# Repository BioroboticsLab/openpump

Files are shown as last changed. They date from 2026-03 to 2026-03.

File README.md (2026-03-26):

# 🌱 OpenPump — Single-Pump Quad-Valve

An open-source, sensor-driven plant watering system built on [ESPHome](https://esphome.io/) and the ESP32. A single pump serves up to **four independent zones** via electronically controlled valves, each with its own soil-moisture sensor, adjustable dryness threshold, and cooldown timer — plus real-time **Telegram notifications**.

> **Branch:** `single_pump_quad_valve` — ESPHome YAML configuration.
> The `main` branch contains the original bare-metal ESP-IDF C firmware for a single-sensor setup.

## Features

- **4-zone watering** — one pump, four valves, four capacitive soil-moisture sensors
- **Per-zone thresholds** — adjustable dryness sliders (0–100) via Home Assistant or the built-in web UI
- **Cooldown protection** — 1-hour cooldown per zone prevents overwatering
- **Pump mutex** — only one zone can pump at a time, preventing pressure issues
- **Telegram alerts** — instant notifications when pumping starts/stops
- **Telegram bot commands** — send `status` for a full report, or `value pod 1` to query a single sensor
- **Heartbeat** — periodic uptime report via Telegram (every 2 hours)
- **Status LED** — blinks during boot/Wi-Fi reconnect, solid when connected
- **Wi-Fi events** — Telegram notification on connect; LED feedback on disconnect
- **OTA updates** — flash new firmware over Wi-Fi
- **Fallback AP** — device creates a hotspot if Wi-Fi is unavailable
- **Web dashboard** — built-in web server on port 80

## Hardware

### 3D-Printed Parts

The enclosure consists of **4 main printed parts** and **1 auxiliary part** printed once per plant zone (up to 4×):

| Part | Description |
|---|---|
| **Box** | Main enclosure: floor and two short side walls. One side wall has a socket for the buck converter with the DC barrel jack hole directly beneath it. The other side wall has a socket for the breadboard. |
| **Wall 1 (Tube Wall)** | Modular wall with half-circle cable management bridges along the top edge and **5 tube holes** at the bottom. The 3rd (middle) hole is the water intake for the pump; the remaining 4 holes are the valve outlets. |
| **Wall 2 (Relay Wall)** | Modular wall with half-circle cable management bridges along the top edge and sliding sockets for the **4-channel relay module** and the **1-channel relay module**. |
| **Lid** | Slides over the finished assembly to close the enclosure. |
| **Sensor Clamp** *(× 1 per zone, max 4)* | Inserted into a pot or reservoir. Contains a tight slot for the capacitive soil-moisture sensor and a hole to secure the outlet tube in place. |

---

### Electronic Components

| Component | Qty | Link |
|---|-----|---|
| ESP32 DevKit | 1 | [AZ-Delivery](https://www.az-delivery.de/products/esp32-nodemcu-module-wlan-wifi-dev-kit-c-development-board-mit-cp2102-und-usb-c-anschluss-esp-32-esp32-wroom-32-kompatibel-mit-ar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) |
| Breadboard (~400 pin, half-size) | 1 | [Conrad](https://www.conrad.de/de/p/velleman-steckplatine-grau-polzahl-gesamt-400-l-x-b-x-h-82-x-8-x-55-mm-1-st-2574925.html) |
| 4-channel relay module | 1 | [Conrad](https://www.conrad.de/de/p/tru-components-tc-9927216-relais-modul-1-st-2481804.html) |
| 1-channel relay module | 1 | [Conrad](https://www.conrad.de/de/p/whadda-wpm406-relais-modul-1-st-2330791.html) |
| Buck converter (12 V → 5 V) | 1 | [AZ-Delivery](https://www.az-delivery.de/products/xl4016e-yh11060d) |
| Capacitive soil-moisture sensor | up to 4 | [AZ-Delivery](https://www.az-delivery.de/products/bodenfeuchte-sensor-modul-v1-2) |
| Peristaltic pump (12 V) | 1 | [Amazon](https://www.amazon.de/Peristaltische-Mini-Peristaltikpumpe-Bioengineering-Silikonschlauch-Aquarienlaboranalytik/dp/B0BTQMRSQ8) |
| Solenoid valve (12 V, NC) | up to 4 | [Amazon](https://www.amazon.de/WITTKOWARE-Mini-Magnetventil-12V-Anschl%C3%BCsse-Positionen/dp/B07JB53SMP) |
| DC barrel jack (2.5 mm) | 1 | [Conrad](https://www.conrad.de/de/p/econ-connect-dce5bp-niedervolt-steckverbinder-chassisbuchse-gerade-2-5-mm-1-st-1303454.html) |
| 12 V / 2 A power supply | 1 | [Conrad](https://www.conrad.de/de/p/dehner-elektronik-sys-1308n-2412-w2e-steckernetzteil-festspannung-12-v-dc-2-a-24-w-stabilisiert-2330693.html) |
| Silicone tube (ID 3.5 mm / OD 4.5 mm) | as needed | any aquarium supplier |
| Spring hose clamps (4 mm) | 8 (2 per valve) | [Amazon](https://amzn.eu/d/0d3o6NUx) |
| T-profile tube connectors (3 mm) | 3 | [Amazon](https://www.amazon.de/BGS-8790-10-Schlauchverbinder-Sortiment-10-mm/dp/B015EKYP7Y) |

---

### Pin Mapping

| GPIO | Function |
|---|---|
| GPIO32 | Soil-moisture sensor 1 (ADC) |
| GPIO33 | Soil-moisture sensor 2 (ADC) |
| GPIO39 | Soil-moisture sensor 3 (ADC) |
| GPIO35 | Soil-moisture sensor 4 (ADC) |
| GPIO17 | Pump — 1-channel relay (active-HIGH) |
| GPIO22 | Valve 1 — 4-channel relay ch.1 (active-HIGH) |
| GPIO21 | Valve 2 — 4-channel relay ch.2 (active-HIGH) |
| GPIO19 | Valve 3 — 4-channel relay ch.3 (active-HIGH) |
| GPIO18 | Valve 4 — 4-channel relay ch.4 (active-HIGH) |
| GPIO2  | Status LED (active-LOW) |
| 3.3 V pin | Shared power rail for all 4 moisture sensors |

---

### Assembly Instructions

**Before you start:** Print all 4 main parts plus one Sensor Clamp per zone. Have a soldering iron, glue, and the step file open to measure the correct breadboard width for the socket.

**1. Soldering**
1. Solder 2 wires onto the DC barrel jack.
2. Solder 2 wires onto the pump.

**2. Prepare the DC barrel jack**
1. Insert the DC barrel jack into the hole beneath the buck converter socket on the side wall of the box.

**3. Prepare the breadboard**
1. Split the breadboard at the center. Before gluing, measure the correct width using the step file so the breadboard fits snugly into its socket.
2. Glue both halves onto a piece of thin cardboard, leaving a small gap so cables can be routed on both sides of the ESP32.
3. Glue the cardboard-mounted breadboard into its socket on the other side wall of the box.
4. Place the ESP32 onto the breadboard.

**4. Install the buck converter and relay modules**
1. Plug the buck converter into its socket on the box wall.
2. Slide the **4-channel relay module** and **1-channel relay module** down into their sockets in Wall 2 (Relay Wall).

**5. Install Wall 1 (Tube Wall)**
1. Fit Wall 1 before gluing the valves to the floor — this makes positioning much easier.
2. Loosely place the solenoid valves and peristaltic pump inside the box.
3. Route the pump intake tube through the **3rd (middle) hole** of Wall 1. Route the 4 valve outlet tubes through the remaining holes. Secure each valve tube with **2 spring hose clamps**.
4. Use **3 T-profile connectors (3 mm)** to split the single pump output tube into 4 lines, one for each valve inlet.

**6. Wiring — Power circuit**

Start by establishing your two power rails on the breadboard (12 V and 5 V):

1. Connect the two wires from the DC barrel jack to the **12 V + and − rows** on one side of the breadboard.
2. Run two cables from the 12 V rows to the **buck converter input** (+ and −).
3. Run the buck converter output cables to the **opposite side** of the breadboard, establishing the **5 V + and − rows**.

You now have a 12 V rail and a 5 V rail available on the breadboard.

**7. Wiring — Valves (4-channel relay module)**

Repeat for each of the 4 valves:

1. Connect the valve's **red (+) cable** directly to the **12 V + row** on the breadboard.
2. Connect the valve's **black (−) cable** to the **middle terminal (COM)** of the corresponding relay channel.
3. Connect a cable from the **right terminal (NO)** of that relay channel to the **12 V − row** on the breadboard.

Then wire the relay module's control circuit:

| Pin | Connection |
|-----|---|
| VCC | 5 V + row on breadboard |
| GND | 5 V − row on breadboard |
| IN1 | GPIO22 (Valve 1) |
| IN2 | GPIO21 (Valve 2) |
| IN3 | GPIO19 (Valve 3) |
| IN4 | GPIO18 (Valve 4) |

**8. Wiring — Pump (1-channel relay module)**

1. Connect the pump's **red (+) cable** directly to the **12 V + row** on the breadboard.
2. Connect the pump's **black (−) cable** to the **middle terminal (COM)** of the single relay.
3. Connect a cable from the **right terminal (NO)** of the relay to the **12 V − row** on the breadboard.

Then wire the relay module's control circuit:

| Pin | Connection |
|-----|---|
| VCC | 5 V + row on breadboard |
| GND | 5 V − row on breadboard |
| IN  | GPIO17 (Pump) |

**9. Wiring — Moisture sensors**

The moisture sensors run on **3.3 V**, not 5 V or 12 V:

1. Run a cable from the ESP32's **3.3 V pin** to a free horizontal row on the breadboard — this becomes your **3.3 V shared row**.
2. For each sensor, plug its **VCC cable** into that same 3.3 V row.
3. Connect each sensor's **GND cable** to the **5 V − row** (common ground).
4. Connect each sensor's **signal (AOUT) cable** to its corresponding GPIO:

| Sensor | GPIO |
|---|---|
| Sensor 1 | GPIO32 |
| Sensor 2 | GPIO33 |
| Sensor 3 | GPIO39 |
| Sensor 4 | GPIO35 |

**10. Final fixation**
1. Once all wiring is complete and verified, glue or screw the pump into position (screw holes are provided).
2. Glue the valves to there sockets.
3. Slide in the second wall (can be kind of tricky).
4. Slide the **Lid** onto the finished assembly.

**11. Install Sensor Clamps**
1. For each plant zone, insert a Sensor Clamp into the pot or reservoir.
2. Slide the moisture sensor into the tight slot.
3. Route the outlet tube through the hole in the clamp to hold it in place.

> ⚠️ **Relay polarity:** Relays are **active-HIGH** — do **not** set `inverted: true` in the ESPHome config. If the pump or a valve runs when it should be OFF, check that you are using COM/NO and not COM/NC on the relay terminals.

## Getting Started

### Prerequisites

- [ESPHome](https://esphome.io/guides/installing_esphome.html) installed (`pip install esphome`)
- A `secrets.yaml` file in the same directory as `valve.yaml`

### Secrets Setup

Create a `secrets.yaml` file alongside `valve.yaml`:
```yaml
ssid: "Your_WiFi_SSID"
password_wifi: "Your_WiFi_Password"
password_ap: "FallbackHotspotPassword"
telegram_bot_token: "123456:ABC-DEF..."
telegram_chat_id: "-100123456789"
api_key: "your-base64-encryption-key"      # generate with: openssl rand -base64 32
ota_password: "a-secure-ota-password"
```

> **Tip:** Create a Telegram bot via [@BotFather](https://t.me/BotFather) and get your chat ID via [@userinfobot](https://t.me/userinfobot).

### Flash the ESP32
```bash
# Validate the configuration
esphome config valve.yaml

# Compile and upload (first time — via USB)
esphome run valve.yaml

# Subsequent updates can be done OTA
esphome run valve.yaml --device labor.local

# Or use the helper script
./flash.sh                              # default: valve.yaml → labor.local
./flash.sh tests/test_actuators.yaml     # flash a test config
./flash.sh valve.yaml 10.94.201.232      # flash to a specific IP
```

### Home Assistant

The device advertises itself via the ESPHome native API. In Home Assistant, go to **Settings → Devices & Services** — the device `labor` should appear for automatic adoption.

## How It Works

1. **Every 30 seconds**, the system checks each zone sequentially.
2. If a zone's moisture reading is **below its threshold** and the **cooldown has expired** and the **pump is not busy**, watering begins:
   - All other valves are closed.
   - The zone's valve opens.
   - The pump runs for the configured **pump duration** (default 30 s, adjustable 5–120 s via slider).
   - A Telegram message is sent at start and stop.
3. A **1-hour cooldown** prevents the same zone from being watered again too soon.
4. The `pump_busy` flag ensures only one zone can pump at a time.
5. A **heartbeat** message is sent via Telegram every 2 hours with the device's uptime.
6. The **Telegram bot** polls for incoming commands every 5 seconds — send `status` for a full report (all sensors, thresholds, cooldowns, pump state, uptime), or `value pod 1` through `value pod 4` for a single reading.
7. The **status LED** blinks during boot and Wi-Fi reconnect, and stays solid once connected.
8. If a zone stays **dry for 24 hours**, a persistent dry alert is sent via Telegram.

## Sensor Calibration

The sensors output a raw ADC voltage which is scaled (×100) and then linearly mapped to 0–100 % using:
```
y = -0.53125 × x + 111.25
```

This maps approximately 21 → 100 % (wet) and 209 → 0 % (dry). To tune for your sensors, adjust the formula coefficients in the `lambda` filter of each sensor in `valve.yaml`.

## Project Structure
```
openpump/
├── valve.yaml                    # ESPHome configuration (main file)
├── secrets.yaml                  # Wi-Fi & Telegram credentials (not tracked)
├── flash.sh                      # Build + OTA flash helper script
├── tests/
│   ├── secrets.yaml              # → symlink to ../secrets.yaml
│   ├── test_actuators.yaml       # Minimal pump/valve toggle test
│   ├── test_sensors.yaml         # Sensor + actuator test
│   └── test_gpio_scan.yaml       # All ADC1 GPIO scan
├── LICENSE                       # MIT
└── README.md                     # This file
```

## License

Licensed under the [MIT License](LICENSE).

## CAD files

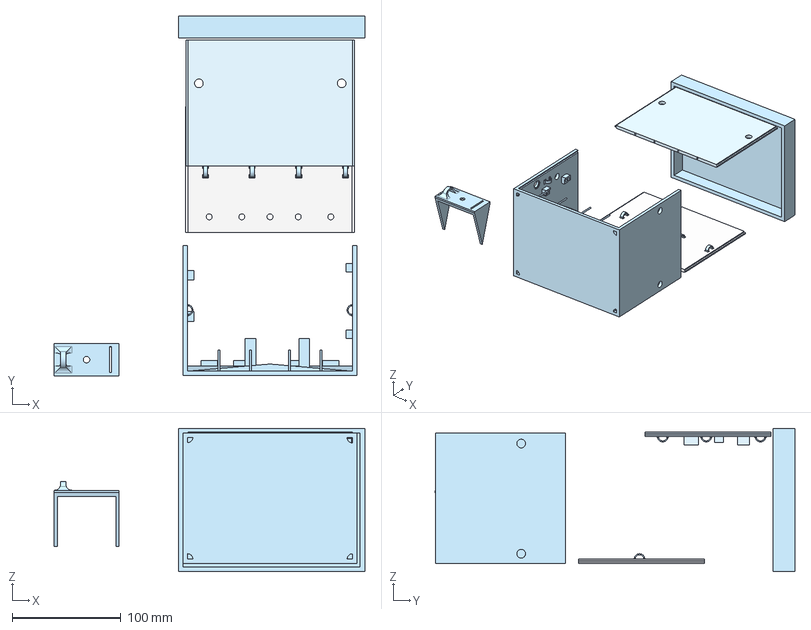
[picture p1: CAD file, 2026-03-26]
box_assembly.step
286.5 x 331.5 x 132.0 mm
Wandmodular 2
Wandmodular 1

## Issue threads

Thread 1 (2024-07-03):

Add switch(es) for manual pump and on-off or auto-manual

timlandgraf, 2024-07-03:
In the current design, you switch the pump on by plugging it into the wall. The device should have an on / off (or automatic / manual) switch, and once we are adding this we could also add buttons for pumping in one or the other direction. This could prove useful in a practical setting. Needs a concept how these switches / buttons behave.

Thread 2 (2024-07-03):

Add status LED(s)

timlandgraf, 2024-07-03:
It would be nice to know in which state the system is currently:

* on / off or automatic / manual mode
* pumping (in case the motor is dead you would still see that the ESP is trying to pump)
* direction of pumping
* errors (like being in failsafe state after motor has been running longer than x seconds)
* warnings (like when the sensor is close to the threshold. once the electrodes are corroded, we can't detect when they're in water anymore)

needs a concept how to encode these things with a minimal number of LEDs

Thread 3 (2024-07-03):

Add sensor for source container

timlandgraf, 2024-07-03:
Currently, the pump stops pumping only when there is water (or whatever liquid you are using) on the sensor. Once the source container is emptied, the pump would pump indefinitely and is only stopped by a failsafe mechanism (a timer). Would be nice if the pump would be able to detect if the contained has been refilled and then starts pumping again.

mirsada, 2024-07-03:
Bluetooth - Feuchtigkeitssensor Xiami Miflora  oder andere Sensoren verwenden ?

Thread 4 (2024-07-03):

OpenPump

mirsada, 2024-07-03:
Als Grundlage für dieses Projekt  dient ein 3D gedrucktes Trink- Gehäuse für die Bienen. Das Gehäuse war so konstruiert, das eine
Glasflache verkehrt herum in das Gehäuse verschraubt wurde, und somit nur die Menge an Zuckerwasser abgeflossen ist, die tatsächlich von den Bienen verbraucht wurde.
Problemlage: Das Zuckerwasser überschwappt durch die Trinköffnungen, und tropft ab. Somit ist unklar, wie hoch der Verbrauch der Bienen tatsächlich ist. Das weitere Problem stellt auch die Verschmutzung der Fläche neben den Öffnungen dar.
Mit einer elektronischen Steuerung einer Pumpe, soll die Füllung der Öffnungen präzisiert werden. Die Fläche, die für die Flasche genutzt wurde, wird mit einem Schlauch versehen, der direkt in das Gehäuse befestigt wird, das andere Ende des Schlauches wird an den steuernden Motor befestigt, der das Zuckerwasser aus einem Gefäß transportiert. Das Gehäuse ist im inneren Hohl, so das nur ein Loch für den Schlauch und die Trinkspalten als Öffnungen des Gehäuses zu erfassen sind.
An der ersten Trinköffnung wird ein Taster platziert, der geschlossen wird sobald er mit Wasser in Berührung steht. Dieser Taster wird mit der elektronischen Komponente verbunden, die für die Regulierung der Pumpe zur Verfügung steht.) Ich :)
ChatGBT verbessert mich so 😊
Als Grundlage für dieses Projekt dient ein mittels 3D-Druck hergestelltes Trinkgehäuse für Bienen. Das Gehäuse wurde so konzipiert, dass eine Glasflasche umgekehrt in das Gehäuse eingeschraubt werden kann, wodurch nur die Menge an Zuckerwasser abfließt, die tatsächlich von den Bienen verbraucht wird.

Problemanalyse: Es wurde beobachtet, dass das Zuckerwasser durch die Trinköffnungen überschwappt und abtropft, was zu einer unklaren Erfassung des tatsächlichen Verbrauchs der Bienen führt. Darüber hinaus tritt eine Verschmutzung der Fläche um die Öffnungen auf.

Um diese Probleme zu lösen, wird eine elektronische Steuerung einer Pumpe implementiert, um die Befüllung der Trinköffnungen zu präzisieren. Der Bereich, der bisher für die Glasflasche genutzt wurde, wird durch einen Schlauch ersetzt, der direkt am Gehäuse befestigt wird. Das andere Ende des Schlauches wird an einen steuerbaren Motor angeschlossen, der das Zuckerwasser aus einem Reservoir fördert.

Das Gehäuse ist im Inneren hohl und besitzt nur eine Öffnung für den Schlauch sowie die Trinkspalten als Zugänge. An der ersten Trinköffnung wird ein Sensor installiert, der aktiviert wird, sobald er mit Wasser in Berührung kommt. Dieser Sensor ist mit der elektronischen Komponente verbunden, die die Regulierung der Pumpe übernimmt.

Diese Anpassung ermöglicht eine präzisere Kontrolle der Zuckerwasserabgabe und reduziert gleichzeitig die Verschmutzung um die Trinköffnungen herum.

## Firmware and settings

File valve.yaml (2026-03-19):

esphome:
  name: labor

  on_boot:
    then:
      - script.execute: led_boot_blink
      - delay: 15s
      - lambda: |-
          id(telegram_ready) = true;

# ── Substitutions ──────────────────────────────────────────────────────
# Centralised constants — change here, applied everywhere.
substitutions:
  telegram_bot_token: !secret telegram_bot_token
  telegram_chat_id: !secret telegram_chat_id

  # Timing (used in lambdas as milliseconds)
  cooldown_ms: "3600000"          # 1 hour between pumps per zone
  check_interval: "30s"
  heartbeat_interval: "2h"        # uptime report via Telegram
  telegram_poll_interval: "5s"    # how often to poll for bot commands

  # Status LED pin (active-low on most ESP32 DevKits)
  led_pin: "GPIO2"

# ── Globals ────────────────────────────────────────────────────────────
globals:
  - id: telegram_ready
    type: bool
    restore_value: false
    initial_value: 'false'
  - id: telegram_message
    type: std::string
    restore_value: false
    initial_value: '""'
  - id: telegram_last_update_id
    type: uint32_t
    restore_value: false
    initial_value: '0'
  - id: telegram_message_ready
    type: bool
    restore_value: false
    initial_value: 'false'
  - id: last_pump_1_ms
    type: uint32_t
    restore_value: false
    initial_value: '0'
  - id: last_pump_2_ms
    type: uint32_t
    restore_value: false
    initial_value: '0'
  - id: last_pump_3_ms
    type: uint32_t
    restore_value: false
    initial_value: '0'
  - id: last_pump_4_ms
    type: uint32_t
    restore_value: false
    initial_value: '0'
  - id: dry_1_start_ms
    type: uint32_t
    restore_value: false
    initial_value: '0'
  - id: dry_2_start_ms
    type: uint32_t
    restore_value: false
    initial_value: '0'
  - id: dry_3_start_ms
    type: uint32_t
    restore_value: false
    initial_value: '0'
  - id: dry_4_start_ms
    type: uint32_t
    restore_value: false
    initial_value: '0'
  - id: dry_1_alerted
    type: bool
    restore_value: false
    initial_value: 'false'
  - id: dry_2_alerted
    type: bool
    restore_value: false
    initial_value: 'false'
  - id: dry_3_alerted
    type: bool
    restore_value: false
    initial_value: 'false'
  - id: dry_4_alerted
    type: bool
    restore_value: false
    initial_value: 'false'
  - id: pump_busy
    type: bool
    restore_value: false
    initial_value: 'false'

# ── Board ──────────────────────────────────────────────────────────────
esp32:
  board: esp32dev
  framework:
    type: esp-idf

logger:
  level: WARN

# ── Network & Security ────────────────────────────────────────────────
api:
  encryption:
    key: !secret api_key
  reboot_timeout: 0s

ota:
  - platform: esphome
    password: !secret ota_password

wifi:
  networks:
    - ssid: !secret ssid
      password: !secret password_wifi
      priority: 0
  power_save_mode: none
  fast_connect: true
  reboot_timeout: 0s

  on_connect:
    then:
      - script.stop: led_boot_blink
      - light.turn_on: status_led
      - if:
          condition:
            lambda: 'return id(telegram_ready);'
          then:
            - http_request.get:
                url: "https://api.telegram.org/bot${telegram_bot_token}/sendMessage?chat_id=${telegram_chat_id}&text=ESP%20connected"

  on_disconnect:
    then:
      - light.turn_off: status_led
      - script.execute: led_boot_blink

  ap:
    ssid: "Labor Fallback Hotspot"
    password: !secret password_ap

captive_portal:

web_server:
  port: 80
  version: 3

http_request:

# ── Manual Controls ───────────────────────────────────────────────────
button:
  - platform: template
    name: "Test Telegram"
    on_press:
      - if:
          condition:
            and:
              - wifi.connected
              - lambda: 'return id(telegram_ready);'
          then:
            - http_request.get:
                url: "https://api.telegram.org/bot${telegram_bot_token}/sendMessage?chat_id=${telegram_chat_id}&text=Test%20message%20from%20ESPHome"

# ── Status LED ─────────────────────────────────────────────────────────
output:
  - platform: gpio
    pin: ${led_pin}
    id: status_led_gpio

light:
  - platform: binary
    output: status_led_gpio
    id: status_led
    name: "Status LED"
    internal: true
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

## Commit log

2024-06-29 added esp32 firmware
2024-06-30 added failsafe timer to avoid motor running indefinitely
2024-06-30 clarified printfs
2024-07-20 changed to capacitive sensor
2024-12-13 added defines for pin levels
2026-01-08 Add valve-based single-pump config
2026-01-09 Add project overview to README.md
    Added detailed project description for Single-Pump Quad-Valve.
2026-03-18 Refactor valve.yaml: security, calibration, pump duration, LED status, Telegram bot, heartbeat
    - Secure API (encryption key) and OTA (password) via !secret
    - Centralize all magic numbers into substitutions
    - Add configurable pump duration slider (5-120s)
    - Calibrate sensors to 0-100% with calibrate_linear + clamp
    - Add status LED with boot blink and WiFi connect/disconnect events
    - Add 2h heartbeat uptime report via Telegram
    - Add Telegram bot command polling (value pot X)
    - Add uptime sensor, persistent dry alert globals
    - WiFi tuning: power_save_mode none, fast_connect, timeout 5s
    - Fix encoding (laeuft), typo (Pod->Pot), add .gitignore
    - Rewrite README with full documentation
    [valve.yaml]
2026-03-18 fix: correct GPIO pins and relay polarity from valve_2.yaml
    Critical hardware fixes:
    - Pump GPIO changed from GPIO5 → GPIO17
    - All switches (pump + 4 valves) now use inverted: true for active-low relays
    - LED output uses inverted pin + internal: true
    - Sensor calibration uses coworker's formula (-0.53125*x + 111.25) + EMA
    - 1s sensor update interval
    - LED blink uses mode: restart with wifi.connected condition
    - Full 24-hour persistent dry alert logic
    - send_telegram script (exact string matching: 'value pod X')
    - Boot delay 15s (matching coworker's version)
    - Kept wifi.connected/telegram_ready guards for stability
    [valve.yaml]
2026-03-18 fix: remove duplicate uptime sensor, stale subs, add WiFi guards
    - Remove duplicate uptime sensor (was defined twice, breaks compile)
    - Remove unused substitutions: sensor_update_interval, cal_wet, cal_dry
    - Replace cooldown timer update_interval refs with literal 5s
    - Add wifi.connected + telegram_ready guards to all 4 dry alerts
    - Add wifi.connected + telegram_ready guard to Test Telegram button
    [valve.yaml]
2026-03-18 add: minimal actuator test program for GPIO polarity check
2026-03-18 fix: remove inverted:true — relays are active-HIGH
    Testing confirmed pump and relay LEDs activate when UI shows OFF,
    meaning the relays are active-HIGH (not active-LOW as assumed).
    Removed inverted: true from all 5 switches and the status LED.
    [valve.yaml]
2026-03-18 Fix GPIO mapping, relay polarity, WiFi stability, add test configs
    Hardware-verified corrections:
    - Sensor 3: GPIO34 → GPIO39
    - Valve GPIOs reversed: V1→GPIO22, V2→GPIO21, V3→GPIO19, V4→GPIO18
    - Relays are active-HIGH (removed inverted: true)
    - WiFi: added power_save_mode: none, fast_connect, reboot_timeout: 0s
    - README: updated pin table, calibration, project structure
    - flash.sh: now accepts config file as first arg
    - New test configs: test_sensors.yaml, test_gpio_scan.yaml
    [valve.yaml]
2026-03-18 fix: README corrections, sync test pin mappings, add pump safety timeout, switch to MIT license
    [valve.yaml]
2026-03-19 fix: make Telegram 'status' command case-insensitive
    [valve.yaml]
2026-03-26 Enhance README with detailed hardware and assembly info
    Expanded the hardware section to include detailed descriptions of 3D-printed parts and electronic components, along with assembly instructions and wiring details.
2026-03-26 added 3d parts
    [box_assembly.step]
